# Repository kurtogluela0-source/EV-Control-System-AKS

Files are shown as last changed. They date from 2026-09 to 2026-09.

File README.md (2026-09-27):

# EV Control System (AKS)

<p align="center">
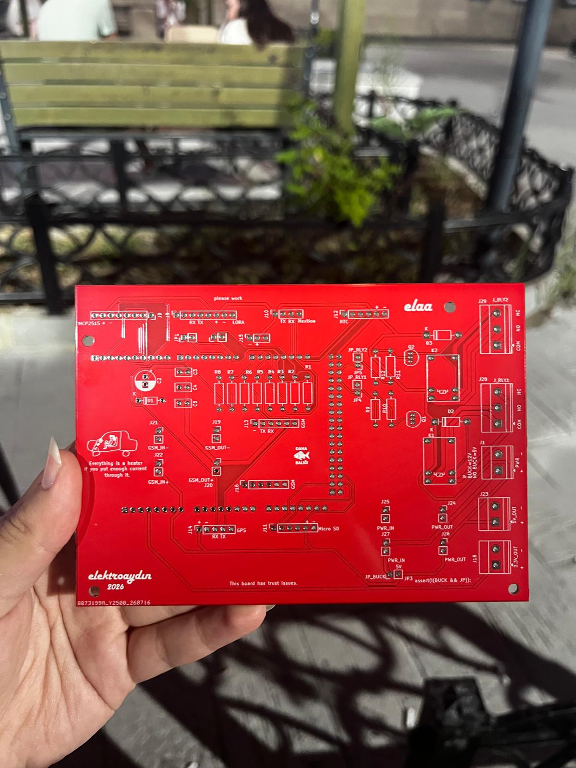
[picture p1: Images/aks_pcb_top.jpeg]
AKS PCB
  
</p>

Custom vehicle control system PCB developed for an electric vehicle project.

## Overview

The AKS (Araç Kontrol Sistemi) is a custom vehicle control and monitoring board designed for an electric vehicle platform.

The system integrates vehicle communication, telemetry, data logging, power management and control interfaces on a single embedded hardware platform.

The project was developed as part of the ElektroAydın electric vehicle team and focuses on practical embedded hardware design, vehicle communication and system integration.

## Key Features

- ATmega2560-based control architecture
- CAN Bus communication using MCP2515
- GSM telemetry using SIM800C
- SD card data logging
- DS3231 Real-Time Clock
- Relay and contactor control
- 12 V vehicle power input
- Regulated 5 V and 3.3 V power rails
- Modular communication and peripheral interfaces

## PCB Design

### 3D View

<p align="center">
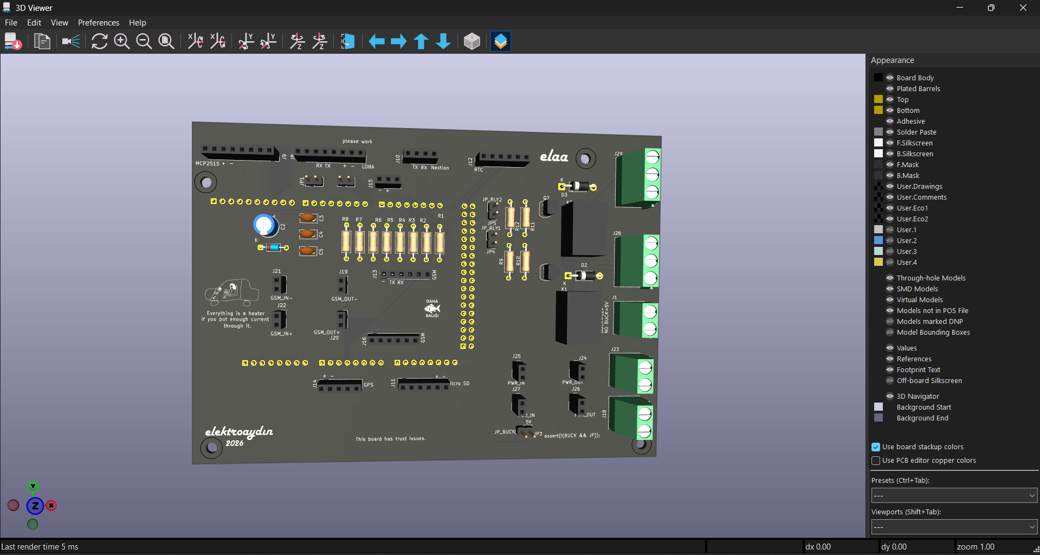
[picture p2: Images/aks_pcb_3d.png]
AKS PCB 3D View
  
</p>

### PCB Layout

<p align="center">
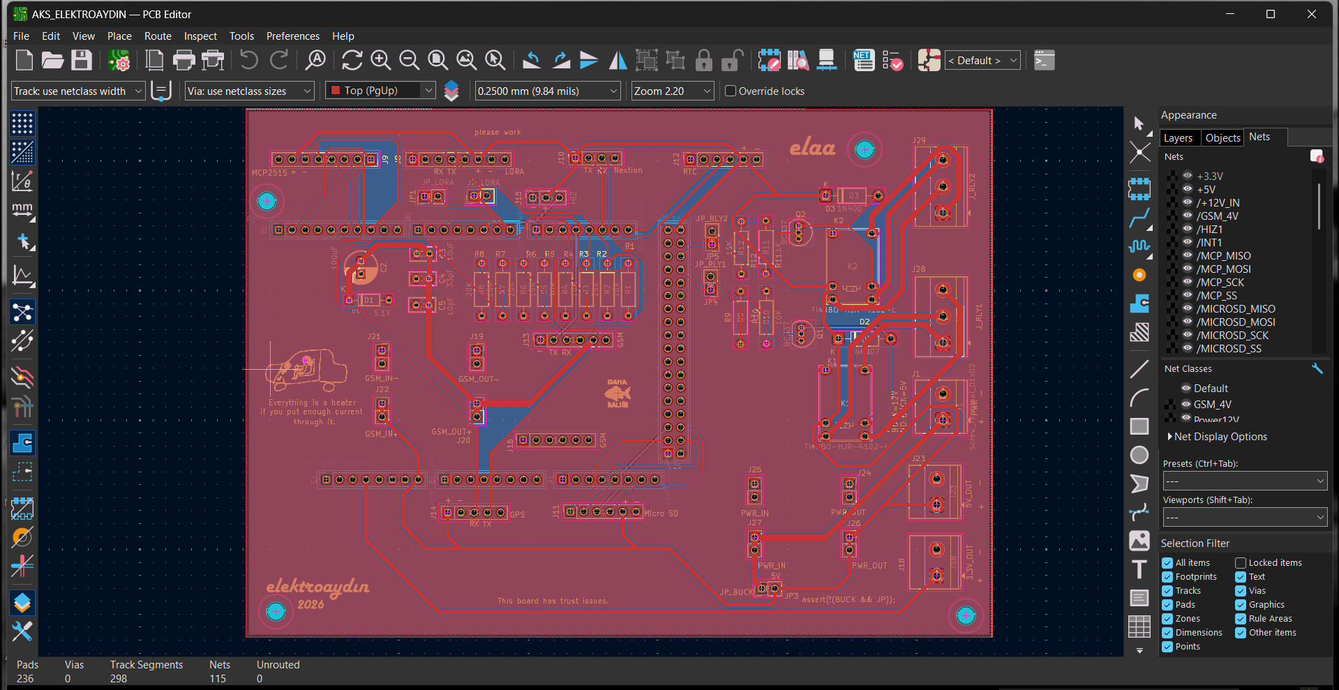
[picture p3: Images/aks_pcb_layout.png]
AKS PCB Layout
  
</p>

## Communication Interfaces

| Interface | Application |
|---|---|
| CAN Bus | Vehicle and BMS communication |
| UART | GSM and external peripheral communication |
| SPI | MCP2515 CAN controller and SD card |
| I2C | DS3231 Real-Time Clock |

## Hardware Architecture

The board is designed around the ATmega2560 platform and provides multiple communication and control interfaces required for electric vehicle applications.

The hardware architecture includes:

- Vehicle CAN communication
- GSM-based telemetry
- External peripheral communication
- Data logging
- Real-time clock functionality
- Relay and contactor control
- Multi-voltage power distribution
- Modular communication interfaces

## Power Architecture

The system is powered from the vehicle's 12 V electrical system.

Voltage regulation stages are used to generate the required supply rails for the control electronics and communication modules.

The board provides:

- 12 V vehicle input
- Regulated 5 V supply
- Regulated 3.3 V supply
- Power distribution for communication modules
- Decoupling and filtering for supply stability

## CAN Bus Integration

CAN Bus communication is implemented using the MCP2515 CAN controller.

The CAN interface enables communication between the AKS and other vehicle systems such as the Battery Management System (BMS).

## GSM Telemetry

A SIM800C GSM module is used for telemetry and remote data communication.

The GSM interface enables selected vehicle data to be transmitted externally when required.

## Relay and Contactor Control

The AKS includes relay control interfaces for switching vehicle systems.

These outputs can be used to control higher-power components such as vehicle contactors through low-power control signals.

## Data Logging

Vehicle data can be stored locally using an SD card interface.

The SD card communicates with the microcontroller using SPI and can be used for:

- Vehicle data logging
- Sensor recording
- CAN data storage
- System monitoring

## Real-Time Clock

A DS3231 Real-Time Clock module is connected using I2C.

The RTC provides timestamp information for logged vehicle data and system events.

## Hardware Testing

The board was evaluated through power verification, communication interface testing, peripheral integration and vehicle-level system testing.

<p align="center">
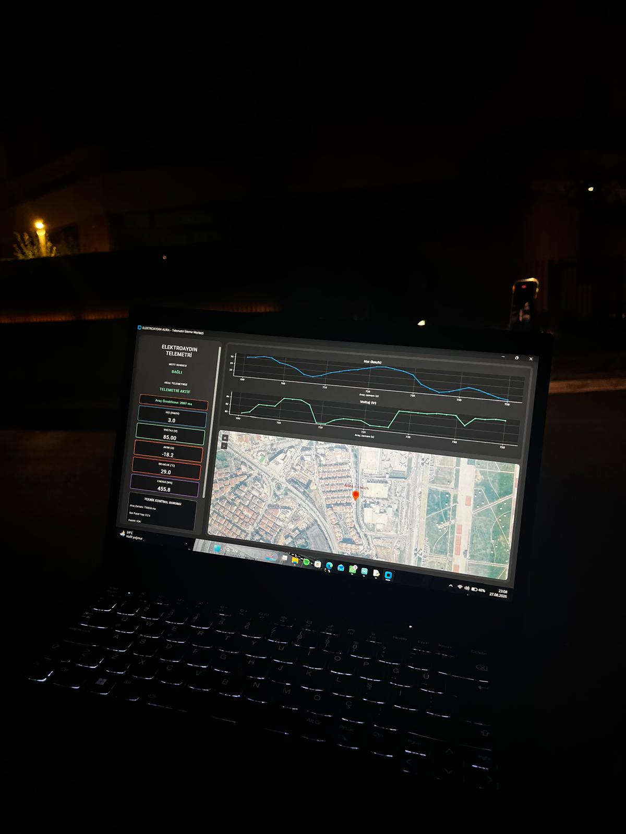
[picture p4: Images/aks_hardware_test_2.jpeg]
AKS Hardware Test 2
  
</p>

## My Contribution

My responsibilities in the project included:

- System architecture design
- Schematic design
- PCB layout
- Component selection
- Power distribution design
- CAN communication hardware integration
- GSM telemetry hardware integration
- Relay and contactor interface design
- Peripheral interface planning
- PCB manufacturing preparation
- Hardware testing
- System integration

## Tools & Technologies

- KiCad
- ATmega2560
- Arduino Mega platform
- CAN Bus
- MCP2515
- SIM800C
- DS3231
- SPI
- UART
- I2C
- PCB Design
- Embedded Systems
- Hardware Testing
- Git
- GitHub

## Project Status

The project was designed, manufactured, tested and integrated as part of an electric vehicle development process.

The current prototype demonstrates vehicle communication, telemetry, data logging, power distribution and control interface integration.

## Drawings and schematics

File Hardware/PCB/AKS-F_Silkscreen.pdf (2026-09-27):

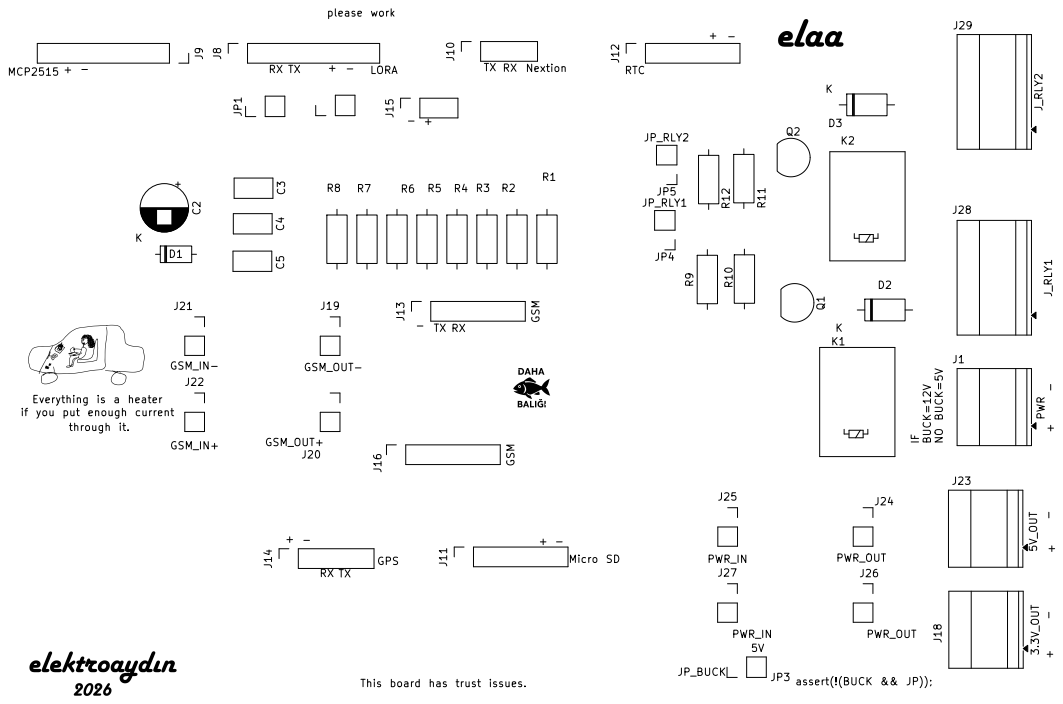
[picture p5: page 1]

please work +
if you put enough current +
This board has trust issues. -

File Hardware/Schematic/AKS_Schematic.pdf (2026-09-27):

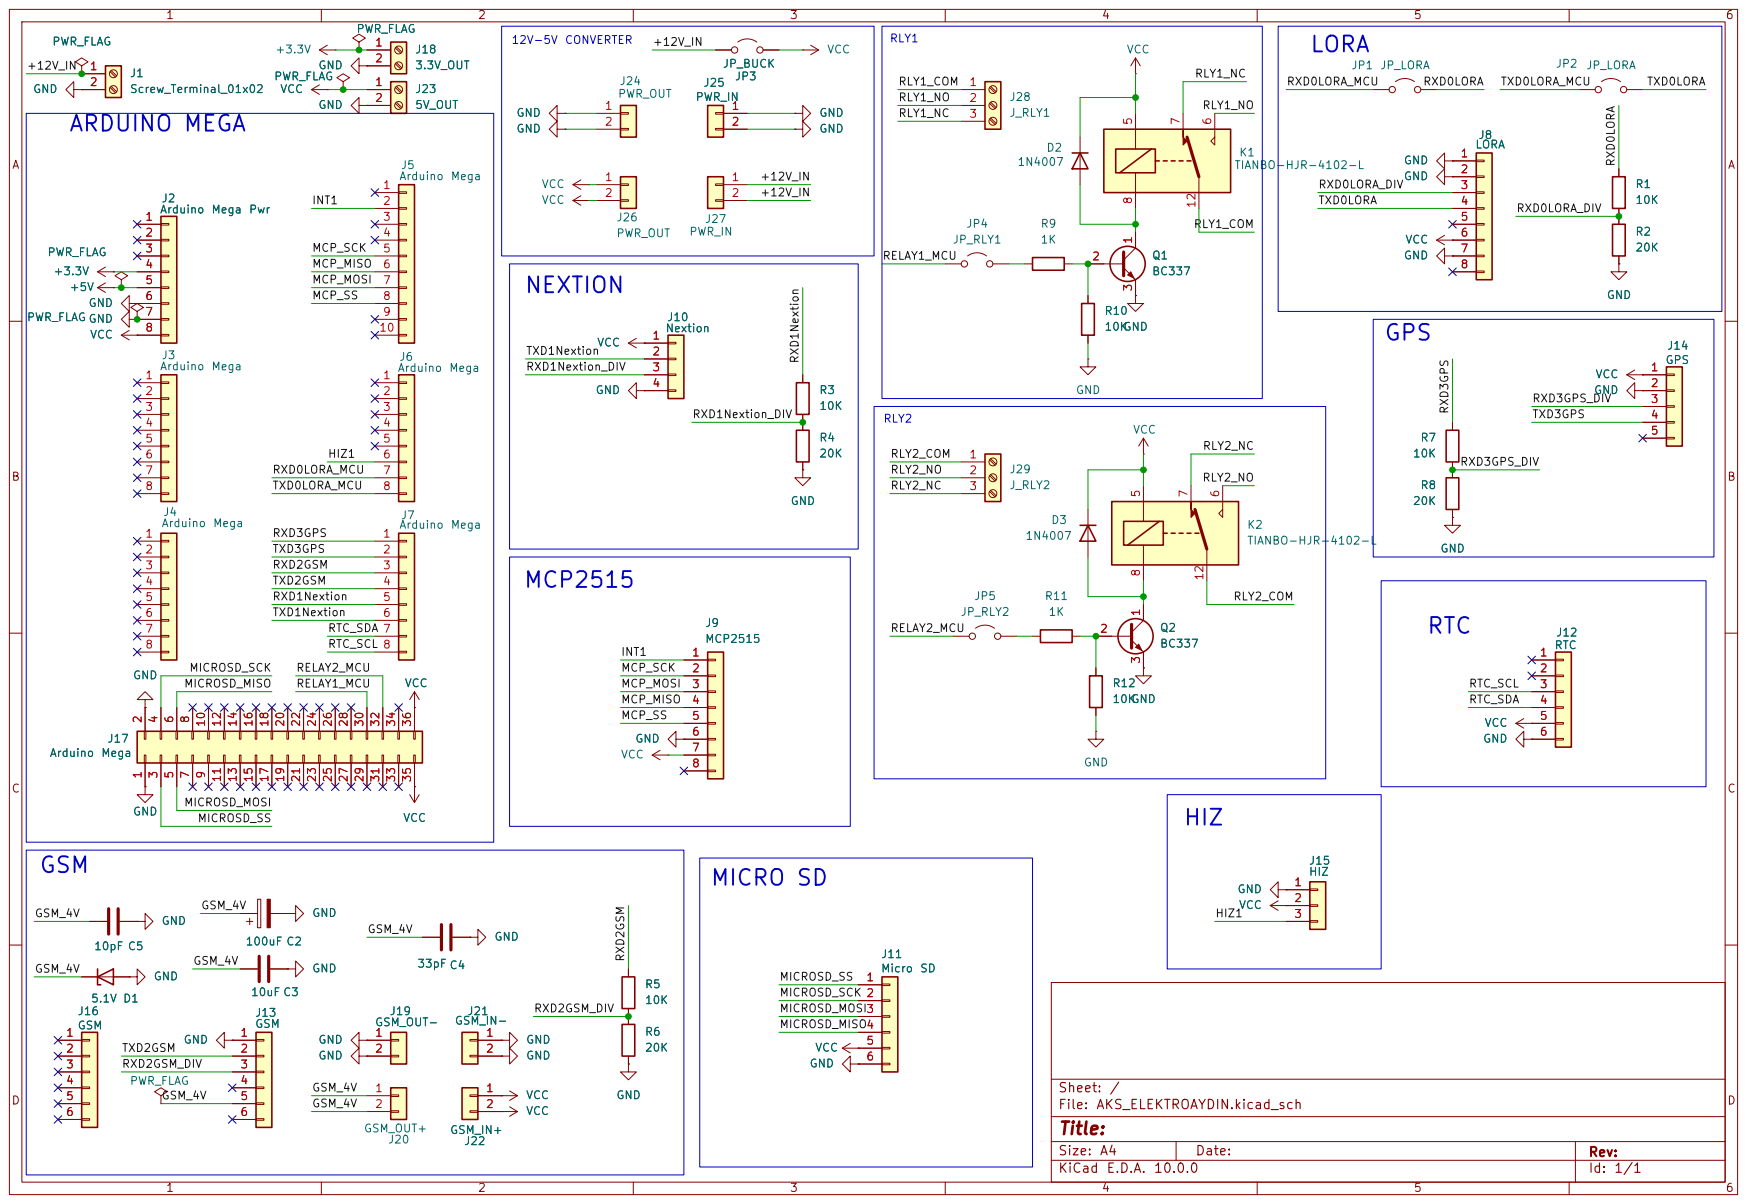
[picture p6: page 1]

Arduino Mega Pwr GND

Size: A4 | Rev:
KiCad E.D.A. 10.0.0 | Id: 1/1

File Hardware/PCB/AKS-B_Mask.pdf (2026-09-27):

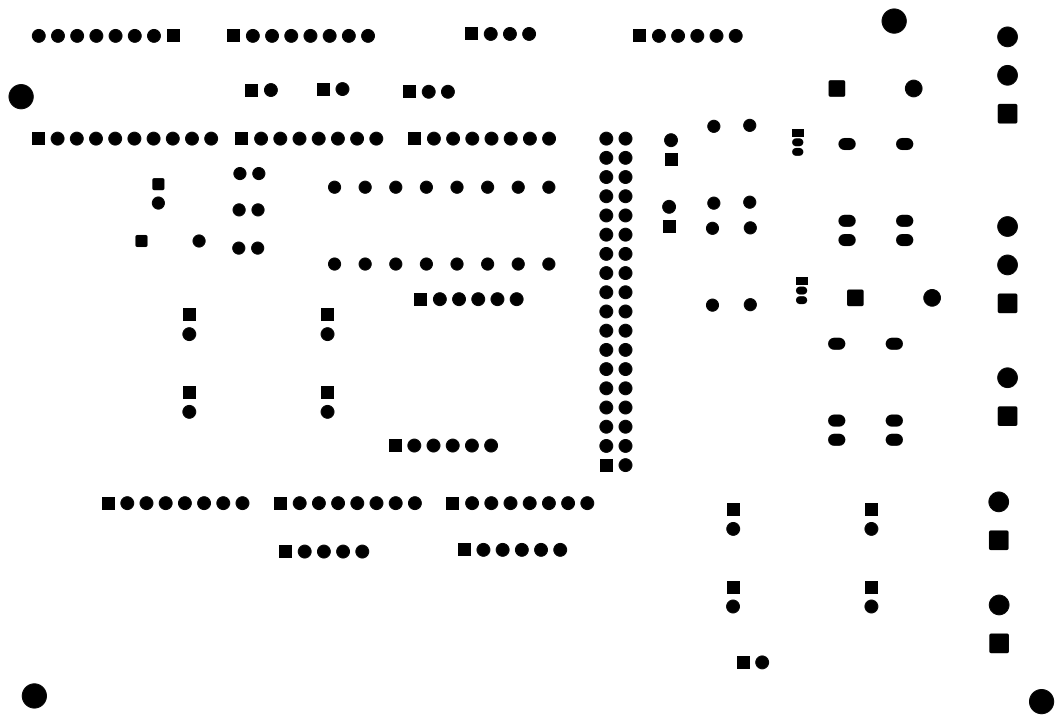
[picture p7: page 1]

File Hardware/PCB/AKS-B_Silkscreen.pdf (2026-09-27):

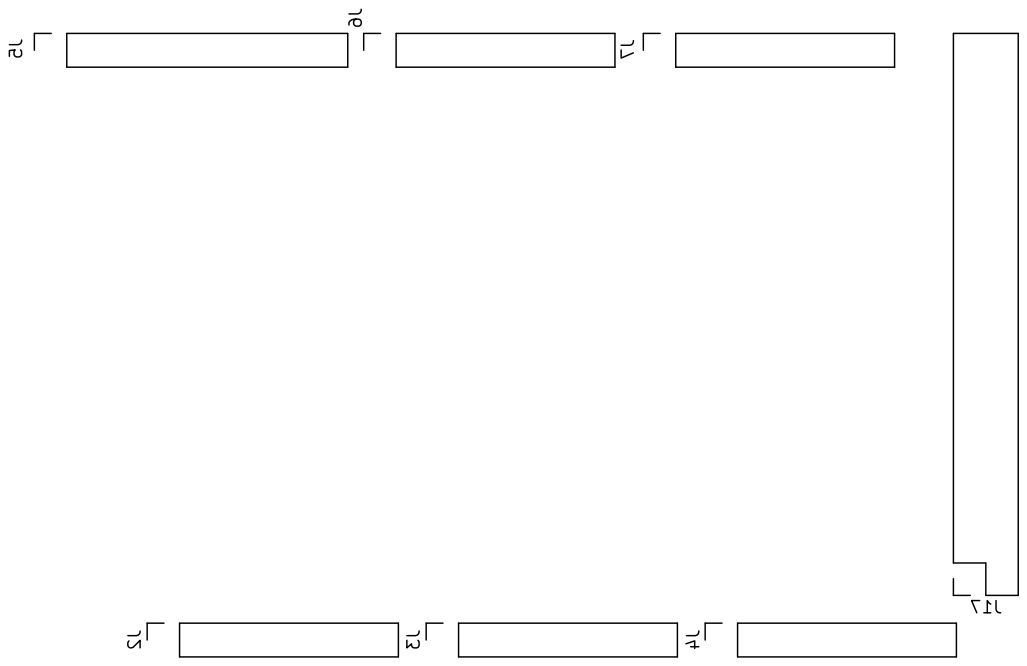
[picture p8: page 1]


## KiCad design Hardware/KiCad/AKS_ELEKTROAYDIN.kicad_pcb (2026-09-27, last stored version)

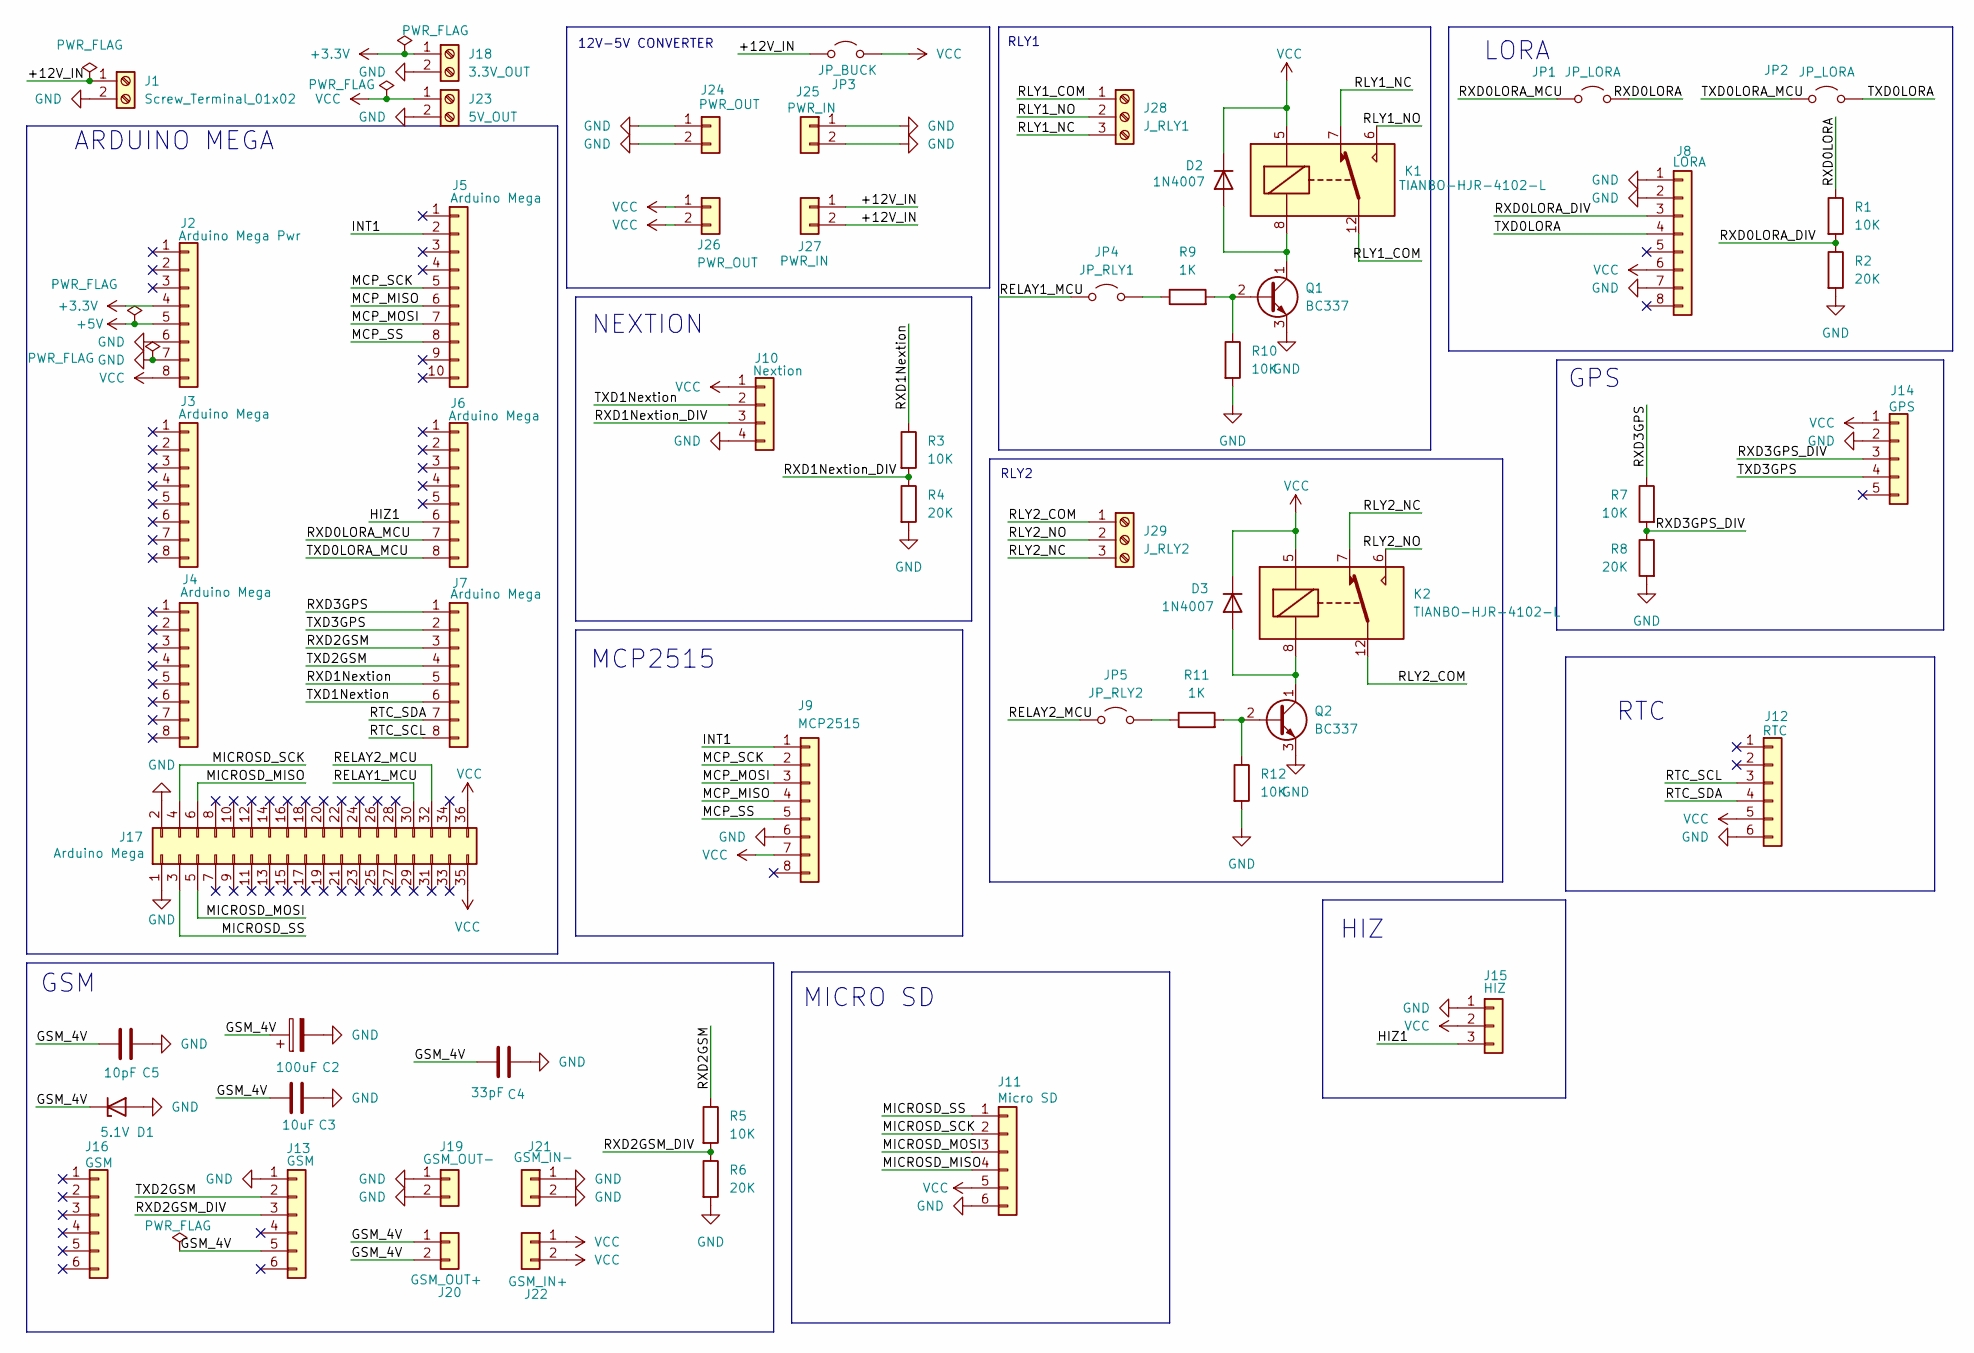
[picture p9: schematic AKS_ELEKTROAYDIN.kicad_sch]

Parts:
C2: 100uF; CP_Radial_D6.3mm_P2.50mm
C3: 10uF; C_Disc_D5.0mm_W2.5mm_P2.50mm
C4: 33pF; C_Disc_D5.0mm_W2.5mm_P2.50mm
C5: 10pF; C_Disc_D5.0mm_W2.5mm_P2.50mm
D1: 5.1V; D_DO-35_SOD27_P7.62mm_Horizontal
D2, D3: 1N4007; D_DO-41_SOD81_P10.16mm_Horizontal
J1: Screw_Terminal_01x02
J2: Arduino Mega Pwr; PinHeader_1x08_P2.54mm_Vertical
J3, J4, J6, J7: Arduino Mega; PinHeader_1x08_P2.54mm_Vertical
J5: Arduino Mega; PinHeader_1x10_P2.54mm_Vertical
J8: LORA; PinSocket_1x08_P2.54mm_Vertical
J9: MCP2515; PinSocket_1x08_P2.54mm_Vertical
J10: Nextion; PinSocket_1x04_P2.54mm_Vertical
J11: Micro SD; PinSocket_1x06_P2.54mm_Vertical
J12: RTC; PinSocket_1x06_P2.54mm_Vertical
J13, J16: GSM; PinSocket_1x06_P2.54mm_Vertical
J14: GPS; PinSocket_1x05_P2.54mm_Vertical
J15: HIZ; PinSocket_1x03_P2.54mm_Vertical
J17: Arduino Mega; PinHeader_2x18_P2.54mm_Vertical
J18: 3.3V_OUT; TerminalBlock_Phoenix_MKDS-1,5-2-5.08_1x02_P5.08mm_Horizont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
J19: GSM_OUT-; PinSocket_1x02_P2.54mm_Vertical
J20: GSM_OUT+; PinSocket_1x02_P2.54mm_Vertical
J21: GSM_IN-; PinSocket_1x02_P2.54mm_Vertical
J22: GSM_IN+; PinSocket_1x02_P2.54mm_Vertical
J23: 5V_OUT; TerminalBlock_Phoenix_MKDS-1,5-2-5.08_1x02_P5.08mm_Horizont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
J24, J26: PWR_OUT; PinSocket_1x02_P2.54mm_Vertical
J25, J27: PWR_IN; PinSocket_1x02_P2.54mm_Vertical
J28: J_RLY1; TerminalBlock_Phoenix_MKDS-1,5-3-5.08_1x03_P5.08mm_Horizont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
J29: J_RLY2; TerminalBlock_Phoenix_MKDS-1,5-3-5.08_1x03_P5.08mm_Horizont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
JP1, JP2: JP_LORA; PinHeader_1x02_P2.54mm_Vertical
JP3: JP_BUCK; PinHeader_1x02_P2.54mm_Vertical
JP4: JP_RLY1; PinHeader_1x02_P2.54mm_Vertical
JP5: JP_RLY2; PinHeader_1x02_P2.54mm_Vertical
K1, K2: TIANBO-HJR-4102-L; Relay_SPDT_HJR-4102
Q1, Q2: BC337; TO-92_Inline
R1, R3, R5, R7, R10, R12: 10K; R_Axial_DIN0207_L6.3mm_D2.5mm_P10.16mm_Horizontal
R2, R4, R6, R8: 20K; R_Axial_DIN0207_L6.3mm_D2.5mm_P10.16mm_Horizontal
R9, R11: 1K; R_Axial_DIN0207_L6.3mm_D2.5mm_P10.16mm_Horizontal

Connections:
+3.3V: J2.4, J18.1
+5V: J2.5
/+12V_IN: J1.1, J27.1, J27.2, JP3.1 (A)
/GSM_4V: C2.1, C3.2, C4.1, C5.1, D1.1 (K), J13.5, J20.1, J20.2
/HIZ1: J6.6, J15.3
/INT1: J5.2, J9.1
/MCP_MISO: J5.6, J9.4
/MCP_MOSI: J5.7, J9.3
/MCP_SCK: J5.5, J9.2
/MCP_SS: J5.8, J9.5
/MICROSD_MISO: J11.4, J17.6
/MICROSD_MOSI: J11.3, J17.5
/MICROSD_SCK: J11.2, J17.4
/MICROSD_SS: J11.1, J17.3
/RELAY1_MCU: J17.30, JP4.1 (A)
/RELAY2_MCU: J17.32, JP5.1 (A)
/RLY1_COM: J28.1, K1.12
/RLY1_NC: J28.3, K1.7
/RLY1_NO: J28.2, K1.6
/RLY2_COM: J29.1, K2.12
/RLY2_NC: J29.3, K2.7
/RLY2_NO: J29.2, K2.6
/RTC_SCL: J7.8, J12.3
/RTC_SDA: J7.7, J12.4
/RXD0LORA: JP1.2 (B), R1.1
/RXD0LORA_DIV: J8.3, R1.2, R2.1
/RXD0LORA_MCU: J6.7, JP1.1 (A)
/RXD1Nextion: J7.5, R3.1
/RXD1Nextion_DIV: J10.3, R3.2, R4.1
/RXD2GSM: J7.3, R5.1
/RXD2GSM_DIV: J13.3, R5.2, R6.1
/RXD3GPS: J7.1, R7.1
/RXD3GPS_DIV: J14.3, R7.2, R8.1
/TXD0LORA: J8.4, JP2.2 (B)
/TXD0LORA_MCU: J6.8, JP2.1 (A)
/TXD1Nextion: J7.6, J10.2
/TXD2GSM: J7.4, J13.2
/TXD3GPS: J7.2, J14.4
GND: C2.2, C3.1, C4.2, C5.2, D1.2 (A), J1.2, J2.6, J2.7, J8.1, J8.2, J8.7, J9.6, J10.4, J11.6, J12.6, J13.1, J14.2, J15.1, J17.1, J17.2, J18.2, J19.1, J19.2, J21.1, J21.2, J23.2, J24.1, J24.2, J25.1, J25.2, Q1.3 (E), Q2.3 (E), R2.2, R4.2, R6.2, R8.2, R10.2, R12.2
unnamed: D2.2 (A), K1.8, Q1.1 (C)
unnamed: D3.2 (A), K2.8, Q2.1 (C)
unnamed: JP4.2 (B), R9.1
unnamed: JP5.2 (B), R11.1
unnamed: Q1.2 (B), R9.2, R10.1
unnamed: Q2.2 (B), R11.2, R12.1
VCC: D2.1 (K), D3.1 (K), J2.8, J8.6, J9.7, J10.1, J11.5, J12.5, J14.1, J15.2, J17.35, J17.36, J22.1, J22.2, J23.1, J26.1, J26.2, JP3.2 (B), K1.5, K2.5

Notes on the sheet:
GPS
12V-5V CONVERTER
MCP2515
RTC
RLY1
ARDUINO MEGA
NEXTION
LORA
HIZ
MICRO SD
GSM
RLY2

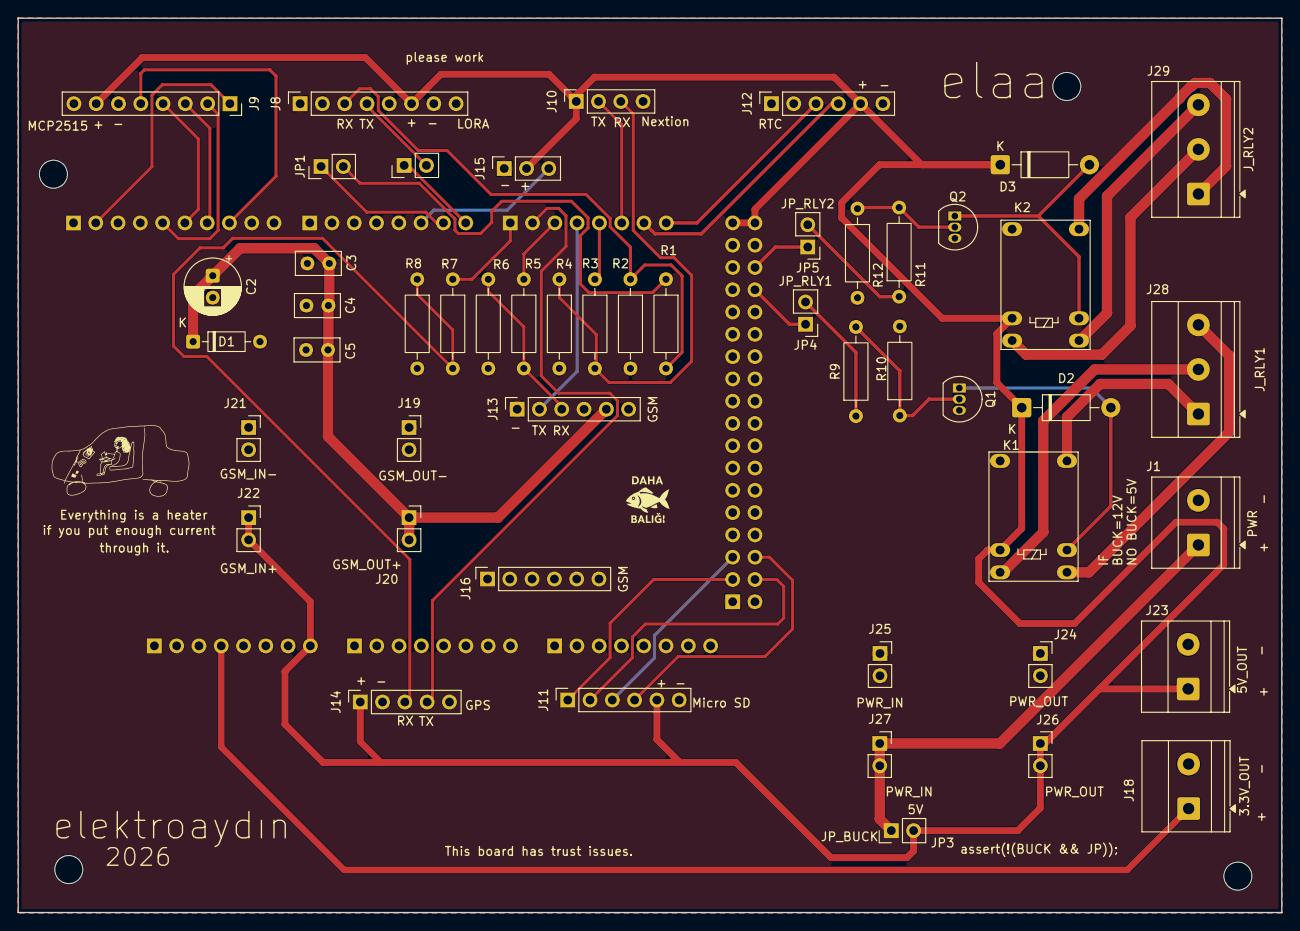
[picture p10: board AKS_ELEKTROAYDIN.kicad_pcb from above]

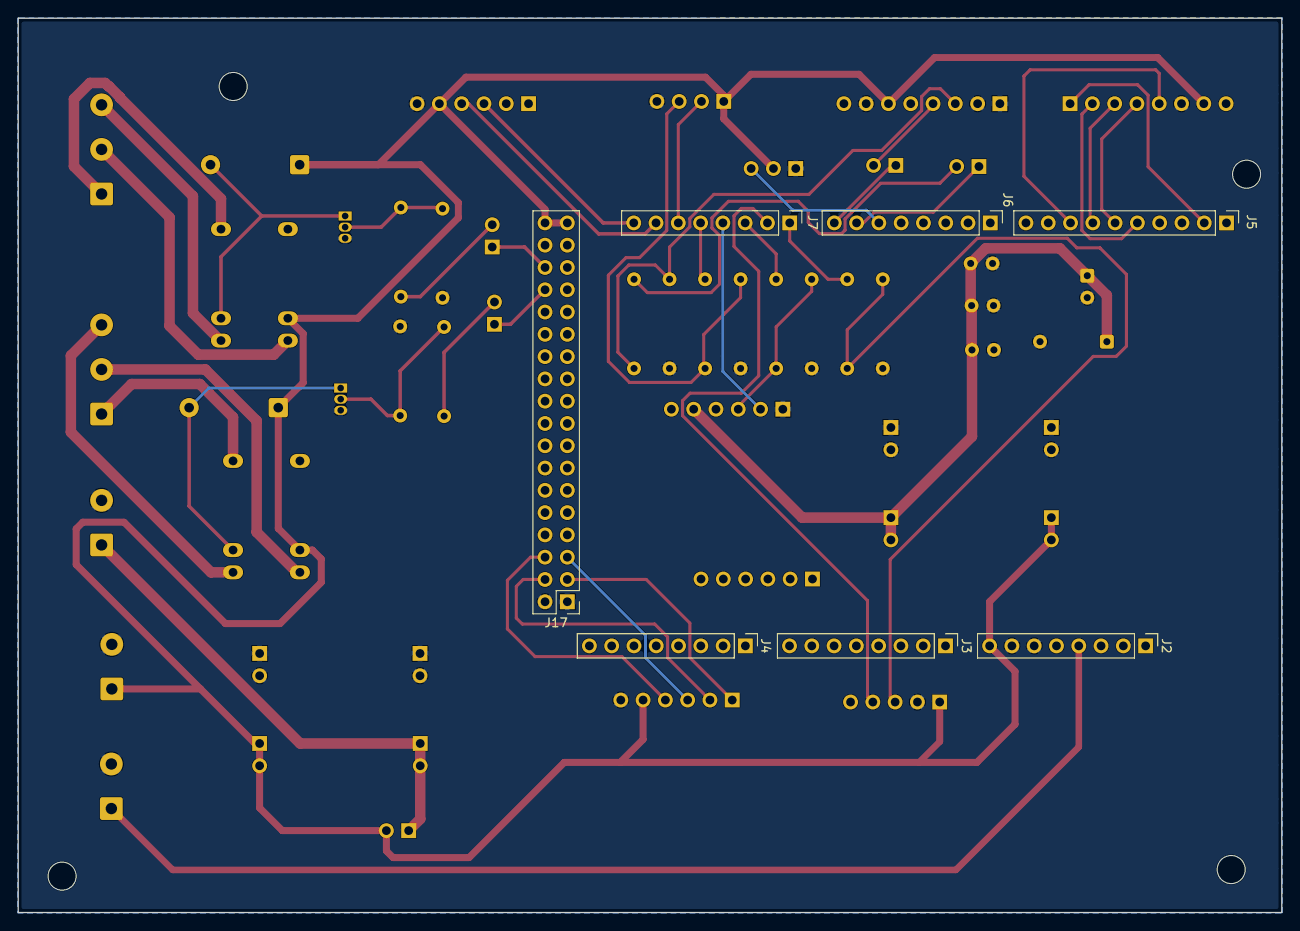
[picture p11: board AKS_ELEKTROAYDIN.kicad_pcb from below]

Board: 2 copper layers, 144.0 x 101.9 mm, 57 parts (7 on the bottom side), 45 nets.

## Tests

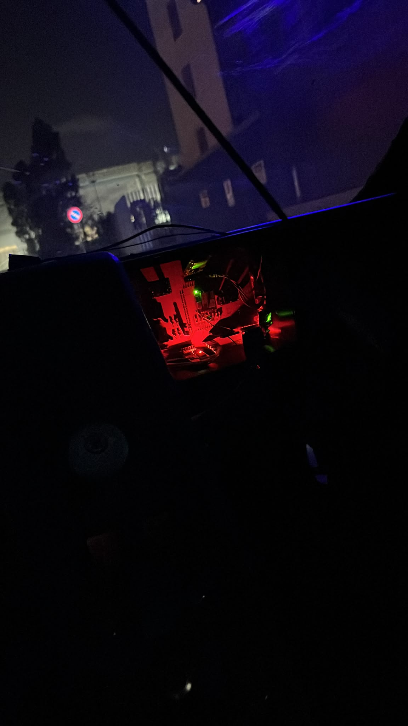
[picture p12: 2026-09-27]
Images/aks_hardware_test..png

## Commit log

2026-09-27 Add PCB image to README
2026-09-27 Create schematic directory
2026-09-27 Create PCB directory
2026-09-27 Create KiCad directory
2026-09-27 Remove KiCad source file
    [AKS_ELEKTROAYDIN.kicad_pcb]
